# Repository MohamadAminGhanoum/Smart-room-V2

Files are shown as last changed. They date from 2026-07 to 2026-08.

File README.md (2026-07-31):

# Smart-room-V2
I have since around 1 year done a smart room, where i made a custom pcb, and salvaged some parts from an old laptop motherboard to be able to control the LED strip that i have and also open and close my curtain, but that was all my thing could do, this time, im planning on making my pcb using jlcpcb instead of for better quality, and im planning on adding a lot more features, such as a screen, CAD and sensor and this stuff.

Note: The Firmware is currently only a test rn, i will upload a working code, once i make this work.

If you are interested, you can check out my V1 of this, with diy pcb: https://github.com/MohamadAminGhanoum/Smart-home

## Schematics:



## PCB + 3d view:




## Fully assembled CAD:





## BOM

|Id |Designator |Footprint |Quantity |Price in USD|Designation |Supplier and ref|Link |
|---|---|---|---|---|---|---|---|
|1  |R14,R13,R10,R15,R12,R11 |R_0603_1608Metric |6 |0 |4.7k |Self-sourced |https://www.lcsc.com/product-detail/C99782.html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 |
|2  |2pins socket |PinSocket_1x02_P2.54mm_Vertical |15 |1.38 |female socket |LCSC |https://www.lcsc.com/product-detail/C7499322.html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 |
|3  |R4 |R_0603_1608Metric |1 |0 |1k |self-sourced |https://www.lcsc.com/product-detail/C22548.html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 |
|4  |R |R_0603_1608Metric |100 |0.51 |0.1R |LCSC |https://www.lcsc.com/product-detail/C3013345.html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 |
|5  |R9,R16,R5,R7,R3,R2,R17,R18  |R_0603_1608Metric |8 |0 |10k |self-sourced |https://www.lcsc.com/product-detail/C2930027.html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 |
|6  |C15,C8,C12,C1 |C_0603_1608Metric |50 |1.15 |1uF |LCSC |https://www.lcsc.com/product-detail/C29936.html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 |
|7  |Q1 |SOT-23 |20 |0.74 |AO3400A |LCSC |https://www.lcsc.com/product-detail/C347475.html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 |
|8  |L1 |L_10.4x10.4_H4.8 |5 |0.4 |22uH |LCSC |https://www.lcsc.com/product-detail/C5349702.html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 |
|9  |E-ink |PinSocket_1x08_P2.54mm_Vertical |5 |1.69 |E-ink waveshare |lcSC |https://www.lcsc.com/product-detail/C2848409.html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 |
|10 |U1 |ESP32-S3-WROOM-1 |2 |9.37 |ESP32-S3-WROOM-1 |LCSC |https://www.lcsc.com/product-detail/C2913197.html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 |
|11 |U6 |Sensirion_DFN-4_1.5x1.5mm_P0.8mm_SHT4x_NoCentralPad|2 |1.91 |SHT4x |LCSC |https://www.lcsc.com/product-detail/C54946589.html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 |
|12 |SW1 |SW_SPST_TS-1088-xR020 |1 |0 |Boot |Self-sourced |N/A |
|13 |C2,C14,C9,C10,C3,C13 |C_0603_1608Metric |20 |1.9 |10uF |LCSC |https://www.lcsc.com/product-detail/C96446.html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 |
|14 |R1 |R_0603_1608Metric |100 |0.39 |6.8k |LCSC |https://www.lcsc.com/product-detail/C844805.html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 |
|15 |C16,C11 |C_0603_1608Metric |2 |0 |100nF |self-sourced |https://www.lcsc.com/product-detail/C1591.html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 |
|16 |RV1 |JST_XH_B3B-XH-A_1x03_P2.50mm_Vertical |5 |2.7 |R_Potentiometer |aliexpress |https://www.aliexpress.com/item/1005003161558340.html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|
|17 |BT1 |BatteryHolder_Keystone_1058_1x2032 |2 |2.74 |Battery_Cell |LCSC |https://www.lcsc.com/product-detail/C5470546.html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 |
|18 |D2,D3 |D_SMA |20 |0.54 |SS34 |LCSC |https://www.lcsc.com/product-detail/C2837271.html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 |
|19 |R8 |R_0603_1608Metric |100 |0.21 |100R |LCSC |https://www.lcsc.com/product-detail/C2906981.html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 |
|20 |R19,R20 |R_0603_1608Metric |2 |0 |33R |self-sourced |https://www.lcsc.com/product-detail/C2909394.html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 |
|21 |C4 |C_0603_1608Metric |50 |0.8 |0.01uF |LCSC |https://www.lcsc.com/product-detail/C100042.html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 |
|22 |C17,C7 |CP_Elec_6.3x7.7 |5 |0.55 |220uF |LCSC |https://www.lcsc.com/product-detail/C2827940.html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 |
|23 |R6 |R_0603_1608Metric |100 |0.3 |3.24k |LCSC |https://www.lcsc.com/product-detail/C22994.html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 |
|24 |C5,C6 |C_0603_1608Metric |2 |0 |4.7uF |self-sourced |https://www.lcsc.com/product-detail/C6119856.html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 |
|25 |U4 |SSOP-10-1EP_3.9x4.9mm_P1mm_EP2.1x3.3mm |4 |1.96 |CH224K |lcSC |https://www.lcsc.com/product-detail/C970725.html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 |
|26 |U7 |SOIC-8_3.9x4.9mm_P1.27mm |1 |0 |Motor controller, AM4969 |self-sourced |From robot vacuum |
|27 |D1 |D_SMC |5 |1.13 |B340 |lcSC |https://www.lcsc.com/product-detail/C110486.html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 |
|28 |C18 |C_0603_1608Metric |1 |0 |0.1uF |self-sourced |https://www.lcsc.com/product-detail/C1591.html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 |
|29 |U5 |SOIC-16W_7.5x10.3mm_P1.27mm |1 |8.77 |DS3231M |lcSC |https://www.lcsc.com/product-detail/C37663.html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 |
|30 |U3 |SOT-23-5 |5 |0.84 |AP2112K-3.3 |lcSC |https://www.lcsc.com/product-detail/C51118.html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 |
|31 |U2 |TI_SO-PowerPAD-8_ThermalVias |2 |1.98 |TPS5430DDA |lcSC |https://www.lcsc.com/product-detail/C9864.html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 |
|32 |J1 |USB_C_Receptacle_XKB_U262-16XN-4BVC11 |5 |0.85 |USB_C_Receptacle_USB2.0_14P|lcSC |https://www.lcsc.com/product-detail/C165948.html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 |
|33 |SW2 |SW_SPST_TS-1088-xR020 |1 |0 |EN |self-sourced |N/A |
|34 |PCB |JLCPCB |5 |4 |JLCPCB |JLCPCB |N/A |
|35 |CAD |JLC3DP |1 |13 |CAD |CAD |N/A |
|36 |40 pin IDC male to male |Kiwi electronics |1 |4.26 |N/A |KIWI electronics|https://www.kiwi-electronics.com/en/40-pin-idc-connector-to-male-jumperwires-20cm-3017?search=male%20to%20male |
|37 |Potentiometer 10k |Kiwi electronics |2 |2.53 |N/A |KIWI electronics|https://www.kiwi-electronics.com/en/panel-mount-10k-potentiometer-breadboard-friendly-1783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 |
|38 |Universal e-Paper Driver HAT|Kiwi electronics |1 |13.94 |N/A |KIWI electronics|https://www.kiwi-electronics.com/en/universal-e-paper-driver-hat-10267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 |
| | | | | | | | |
| | | | | | | | |
| | | |Total price with shipping + vat + tax|107.54 | | | |

### NOTE: I have used my hardware grant to buy many components, therefore the price will be lower when im going to buy the parts.

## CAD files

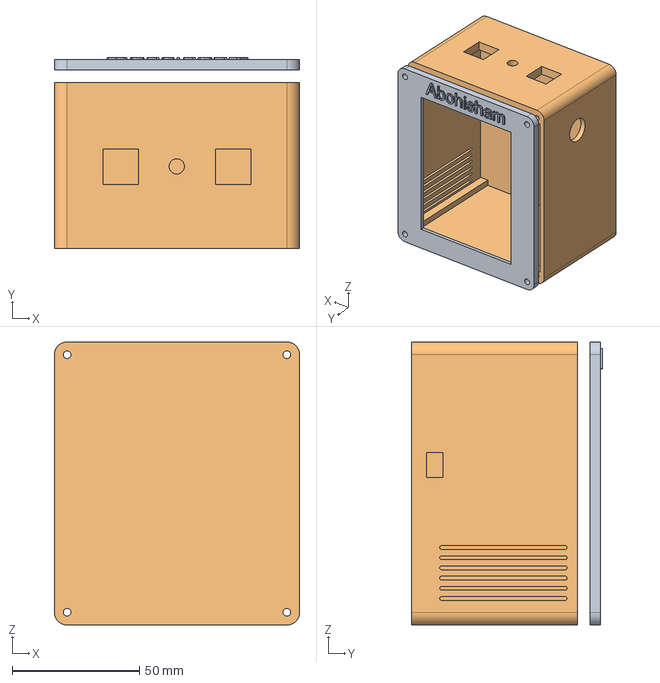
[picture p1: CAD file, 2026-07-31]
Case/CAD.step
96.2 x 74.8 x 111.0 mm

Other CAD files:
Case/CAD.f3z

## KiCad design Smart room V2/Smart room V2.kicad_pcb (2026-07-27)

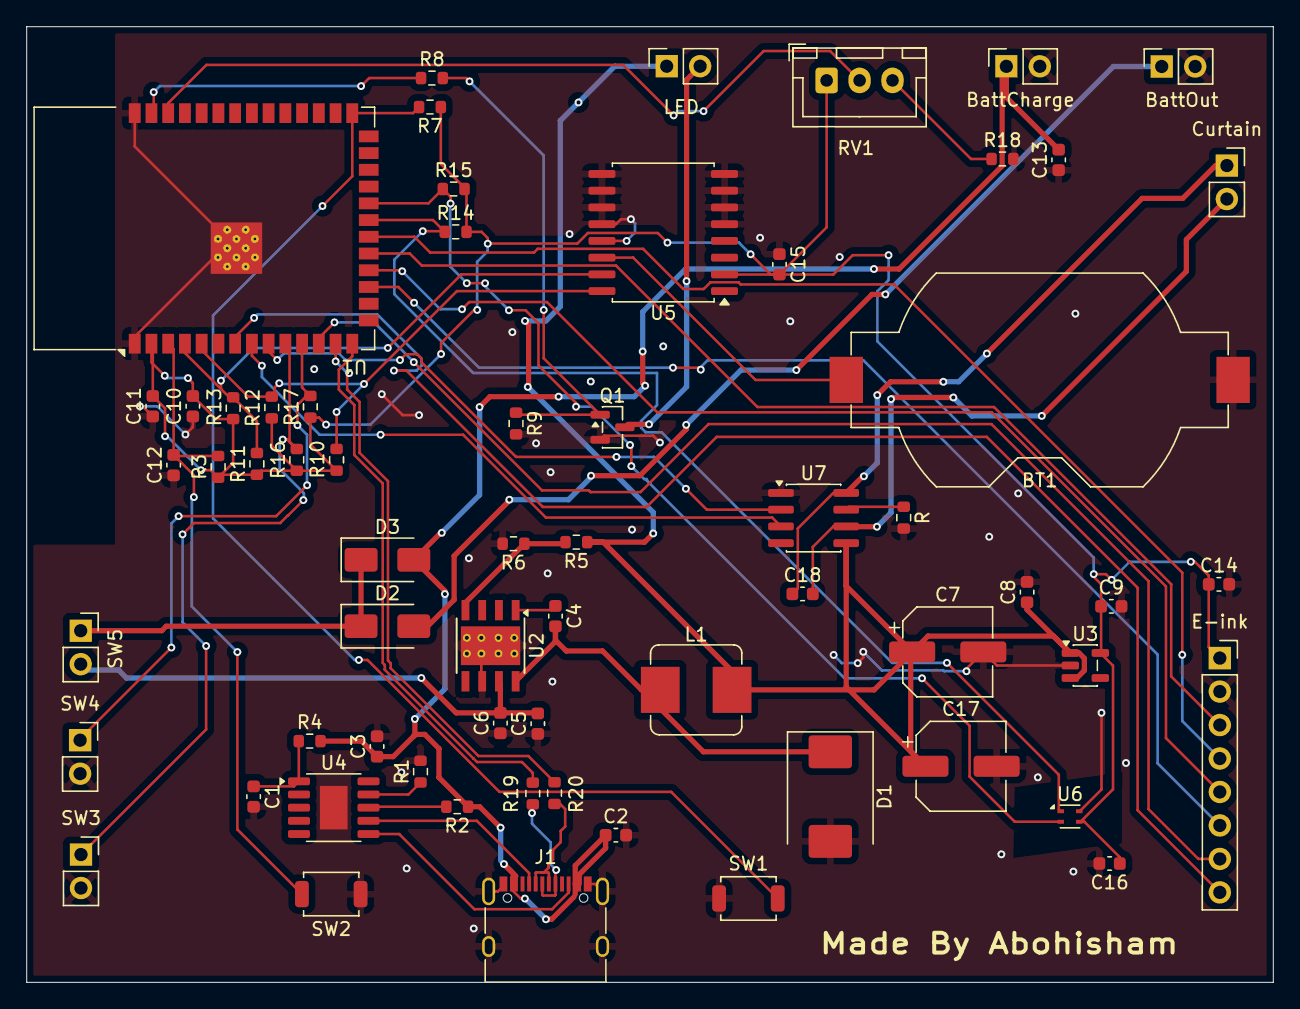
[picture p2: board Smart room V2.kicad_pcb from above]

Board: 2 copper layers, 94.6 x 72.5 mm, 64 parts (0 on the bottom side), 44 nets.

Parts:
BT1: Battery_Cell; BatteryHolder_Keystone_1058_1x2032
BattCharge: Batt_Charge; PinSocket_1x02_P2.54mm_Vertical
BattOut: Batt_output; PinSocket_1x02_P2.54mm_Vertical
C1, C8, C12, C15: 1uF; C_0603_1608Metric
C2, C3, C9, C10, C13, C14: 10uF; C_0603_1608Metric
C4: 0.01uF; C_0603_1608Metric
C5, C6: 4.7uF; C_0603_1608Metric
C7, C17: 220uF; CP_Elec_6.3x7.7
C11, C16: 100nF; C_0603_1608Metric
C18: 0.1uF; C_0603_1608Metric
Curtain: Curtain; PinSocket_1x02_P2.54mm_Vertical
D1: B340; D_SMC
D2, D3: SS34; D_SMA
E-ink: E-ink waveshare; PinSocket_1x08_P2.54mm_Vertical
J1: USB_C_Receptacle_USB2.0_14P; USB_C_Receptacle_XKB_U262-16XN-4BVC11
L1: 22uH; L_Bourns_SRP7028A_7.3x6.6mm
LED: LED_STRIP; PinSocket_1x02_P2.54mm_Vertical
Q1: AO3400A; SOT-23
R: 0.1R; R_0603_1608Metric
R1: 6.8k; R_0603_1608Metric
R2, R3, R5, R7, R9, R16, R17, R18: 10k; R_0603_1608Metric
R4: 1k; R_0603_1608Metric
R6: 3.24k; R_0603_1608Metric
R8: 100R; R_0603_1608Metric
R10, R11, R12, R13, R14, R15: 4.7k; R_0603_1608Metric
R19, R20: 33R; R_0603_1608Metric
RV1: R_Potentiometer; JST_XH_B3B-XH-A_1x03_P2.50mm_Vertical
SW1: Boot; SW_SPST_TS-1088-xR020
SW2: EN; SW_SPST_TS-1088-xR020
SW3, SW4: SW_Push; PinSocket_1x02_P2.54mm_Vertical
SW5: POWER switch; PinSocket_1x02_P2.54mm_Vertical
U1: ESP32-S3-WROOM-1
U2: TPS5430DDA; TI_SO-PowerPAD-8_ThermalVias
U3: AP2112K-3.3; SOT-23-5
U4: CH224K; SSOP-10-1EP_3.9x4.9mm_P1mm_EP2.1x3.3mm
U5: DS3231M; SOIC-16W_7.5x10.3mm_P1.27mm
U6: SHT4x; Sensirion_DFN-4_1.5x1.5mm_P0.8mm_SHT4x_NoCentralPad
U7: Motor controller, AM4969; SOIC-8_3.9x4.9mm_P1.27mm

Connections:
+3.3V: C9.1, C10.2, C11.2, C14.1, C15.2, C16.1, E-ink.1 (Vcc), R3.1, R7.1, R10.2, R11.1, R12.2, R13.2, R14.2, R15.2, R16.1, R17.2, RV1.1, U1.2 (3V3), U3.5 (VOUT), U5.2 (VCC), U6.3 (VDD)
+5V: C7.1, C8.1, C17.1, L1.2, LED.1, R5.1, U3.1 (VIN), U3.3 (EN), U7.5 (EN1)
/BUSY: E-ink.8 (BUSY), U1.7 (IO7)
/CC1: J1.A5 (CC1), U4.7 (CC1)
/CC2: J1.B5 (CC2), U4.6 (CC2)
/CLK: E-ink.4 (CLK), U1.20 (IO12)
/CS: E-ink.5 (CS), U1.18 (IO10)
/D+: J1.A6 (D+), J1.B6 (D+), R19.2
/D-: J1.A7 (D-), J1.B7 (D-), R20.1
/DC: E-ink.6 (DC), U1.17 (IO9)
/DIN: E-ink.3 (DIN), U1.19 (IO11)
/IO1: R8.1, U1.39 (IO1)
/IO2: RV1.2, U1.38 (IO2)
/IO15: U1.8 (IO15), U7.3 (NC)
/IO16: U1.9 (IO16), U7.2 (GND)
/RST: E-ink.7 (RST), U1.12 (IO8)
/SCL_CLOC: R10.1, R12.1, U1.5 (IO5), U5.16 (SCL)
/SDA_CLOC: R11.2, R13.1, U1.4 (IO4), U5.15 (SDA)
/SHT_SCL: R15.1, U1.22 (IO14), U6.2 (SCL)
/SHT_SDA: R14.1, U1.21 (IO13), U6.1 (SDA)
/V_bat: D2.1 (K), D3.1 (K), SW5.1 (A)
GND: BT1.2 (-), BattCharge.2, BattOut.2, C1.2, C2.2, C3.2, C5.1, C6.1, C7.2, C8.2, C9.2, C10.1, C11.1, C12.1, C13.1, C14.2, C15.1, C16.2, C17.2, D1.2 (A), E-ink.2 (Gnd), J1.A1 (GND), J1.A12 (GND), J1.B1 (GND), J1.B12 (GND), J1.S1 (SHIELD), Q1.2 (S), R.2, R1.2, R6.2, R9.2, R18.2, SW1.1, SW2.1, SW3.2, SW4.2, U1.1 (GND), U1.40 (GND), U1.41 (GND), U2.6 (GND), U2.9 (GNDPAD), U3.2 (GND), U4.11 (GND), U5.5 (GND), U5.6 (GND), U5.7 (GND), U5.8 (GND), U5.9 (GND), U5.10 (GND), U5.11 (GND), U5.12 (GND), U5.13 (GND), U6.4 (VSS), U7.1 (VIN)
LSS: R.1, U7.7 (VOUT2)
unnamed: BT1.1 (+), U5.14 (VBAT)
unnamed: C4.2, D1.1 (K), L1.1, U2.8 (PH)
unnamed: BattOut.1, D2.2 (A)
unnamed: LED.2, Q1.3 (D)
unnamed: C18.1, Curtain.1, U7.8 (VOUT1)
unnamed: C18.2, Curtain.2, U7.6 (NC)
unnamed: Q1.1 (G), R8.2, R9.1
unnamed: R18.1, RV1.3
unnamed: C5.2, C6.2, SW5.2 (B), U2.7 (VIN)
unnamed: C12.2, R3.2, SW2.2, U1.3 (EN)
unnamed: R7.2, SW1.2, U1.27 (IO0)
unnamed: R16.2, SW3.1, U1.10 (IO17)
unnamed: R17.1, SW4.1, U1.11 (IO18)
unnamed: R19.1, U1.14 (USB_D+)
unnamed: R20.2, U1.13 (USB_D-)
unnamed: C4.1, U2.1 (BOOT)
unnamed: R5.2, R6.1, U2.4 (VSENSE)
unnamed: R1.1, U4.9 (CFG1)
unnamed: R2.2, U4.8 (VBUS)
unnamed: C1.1, R4.1, U4.1 (VDD)
VBUS: BattCharge.1, C2.1, C3.1, C13.2, D3.2 (A), J1.A4 (VBUS), J1.A9 (VBUS), J1.B4 (VBUS), J1.B9 (VBUS), R2.1, R4.2

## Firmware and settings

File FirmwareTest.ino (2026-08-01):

#include <Arduino.h>
#include <Wire.h>
#include <SPI.h>
#include <RTClib.h>
#include <Adafruit_SHT4x.h>
#include <GxEPD2_BW.h>

#define PIN_LED_PWM       1  
#define PIN_POTENTIOMETER 2  

#define PIN_RTC_SDA       4  
#define PIN_RTC_SCL       5

#define PIN_EPD_BUSY      7   
#define PIN_EPD_RST       8
#define PIN_EPD_DC        9
#define PIN_EPD_CS        10
#define PIN_EPD_MOSI      11
#define PIN_EPD_SCK       12

#define PIN_SHT_SDA       13  
#define PIN_SHT_SCL       14

#define PIN_MOTOR_INA     15  
#define PIN_MOTOR_INB     16 

#define PIN_BTN_OPEN      17  
#define PIN_BTN_CLOSE     18  

TwoWire I2C_RTC = TwoWire(0);
TwoWire I2C_SHT = TwoWire(1);

RTC_DS3231 rtc;
Adafruit_SHT4x sht40 = Adafruit_SHT4x();

const int PWM_FREQ = 5000;      
const int PWM_RESOLUTION = 10;  

unsigned long lastSensorRead = 0;
const unsigned long SENSOR_INTERVAL = 5000;

enum MotorState { STOPPED, OPENING, CLOSING };
MotorState currentMotorState = STOPPED;

void stopMotor() {
  digitalWrite(PIN_MOTOR_INA, LOW);
  digitalWrite(PIN_MOTOR_INB, LOW);
  currentMotorState = STOPPED;
  Serial.println("Motor: STOPPED");
}

void openCurtain() {
  digitalWrite(PIN_MOTOR_INB, LOW);
  digitalWrite(PIN_MOTOR_INA, HIGH);
  currentMotorState = OPENING;
  Serial.println("Motor: OPENING CURTAIN");
}

void closeCurtain() {
  digitalWrite(PIN_MOTOR_INA, LOW);
  digitalWrite(PIN_MOTOR_INB, HIGH);
  currentMotorState = CLOSING;
  Serial.println("Motor: CLOSING CURTAIN");
}

void updateLEDBrightness() {
  static int smoothedADC = 0;
  int rawADC = analogRead(PIN_POTENTIOMETER);

  smoothedADC = (smoothedADC * 7 + rawADC) / 8;

  int pwmValue = map(smoothedADC, 0, 4095, 0, 1023);

  if (pwmValue < 15) pwmValue = 0;

  analogWrite(PIN_LED_PWM, pwmValue);
}

void handleButtons() {
  bool openPressed = (digitalRead(PIN_BTN_OPEN) == LOW);
  bool closePressed = (digitalRead(PIN_BTN_CLOSE) == LOW);

  if (openPressed && currentMotorState != OPENING) {
    openCurtain();
    delay(200); 
  } else if (closePressed && currentMotorState != CLOSING) {
    closeCurtain();
    delay(200); 
  } else if (!openPressed && !closePressed && currentMotorState != STOPPED) {
    stopMotor();
  }
}

void setup() {
  Serial.begin(115200);
  delay(1000);
  Serial.println("--- Starting Smart Room Controller ---");

  pinMode(PIN_MOTOR_INA, OUTPUT);
  pinMode(PIN_MOTOR_INB, OUTPUT);
  stopMotor();

  pinMode(PIN_BTN_OPEN, INPUT_PULLUP);
  pinMode(PIN_BTN_CLOSE, INPUT_PULLUP);

  pinMode(PIN_LED_PWM, OUTPUT);
  analogWriteFrequency(PIN_LED_PWM, PWM_FREQ);
  analogWriteResolution(PIN_LED_PWM, PWM_RESOLUTION);

  I2C_RTC.begin(PIN_RTC_SDA, PIN_RTC_SCL, 100000);
  if (!rtc.begin(&I2C_RTC)) {
    Serial.println("Error: DS3231 RTC not found on I2C Bus 1!");
  } else {
    Serial.println("DS3231 RTC Initialized.");
    if (rtc.lostPower()) {
      rtc.adjust(DateTime(F(__DATE__), F(__TIME__)));
    }
  }

  I2C_SHT.begin(PIN_SHT_SDA, PIN_SHT_SCL, 100000);
  if (!sht40.begin(&I2C_SHT)) {
    Serial.println("Error: SHT40 Sensor not found on I2C Bus 2!");
  } else {
    Serial.println("SHT40 Temp/Humidity Sensor Initialized.");
    sht40.setPrecision(SHT4X_HIGH_PRECISION);
  }

  Serial.println("--- Hardware Initialization Complete ---");
}

void loop() {
  updateLEDBrightness();

  handleButtons();

  if (millis() - lastSensorRead >= SENSOR_INTERVAL) {
    lastSensorRead = millis();

    DateTime now = rtc.now();
    Serial.printf("Time: %02d:%02d:%02d\n", now.hour(), now.minute(), now.second());

    sensors_event_t humidity, temp;
    if (sht40.getEvent(&humidity, &temp)) {
      Serial.printf("Temp: %.1f C | Humidity: %.1f %%\n", temp.temperature, humidity.relative_humidity);
    }

    // TODO: Trigger E-Ink Display refresh here with updated values
  }
}

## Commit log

2026-07-31 Add images to README for fully assembled CAD
2026-07-31 Add Smart Room Controller functionality
    This file contains the implementation of a Smart Room Controller using Arduino. It includes functionalities for controlling a motor, reading sensor data, and adjusting LED brightness based on a poten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
2026-07-31 Rename Smart room V2.step to Smart room V2/Smart room V2.step
    [Smart room V2.step]
2026-08-01 Refactor pin definitions and clean up code
